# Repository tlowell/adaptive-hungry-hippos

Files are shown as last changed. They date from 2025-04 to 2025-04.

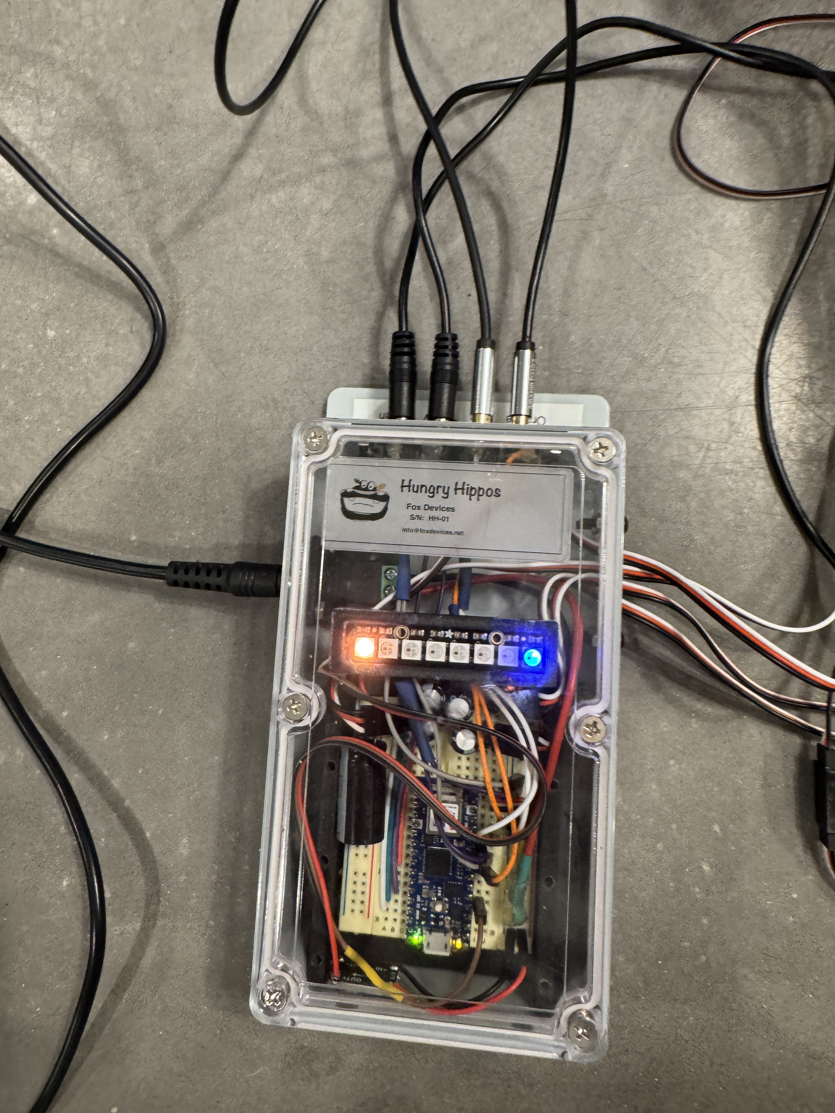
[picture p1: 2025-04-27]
images/lid on.JPG

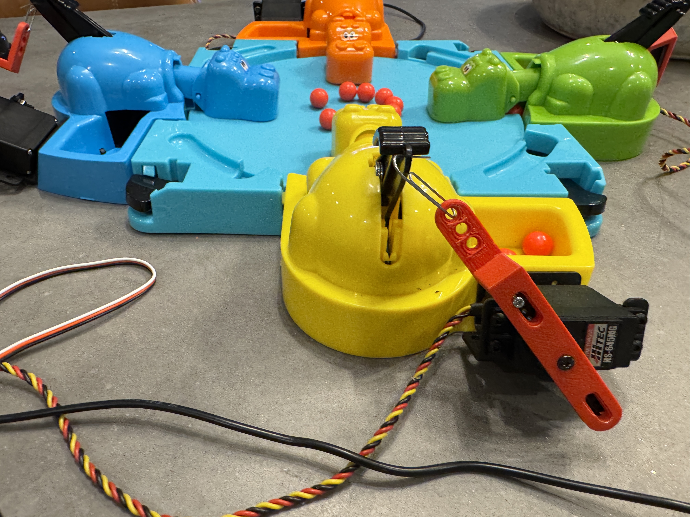
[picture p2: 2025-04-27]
images/servos attached.JPG

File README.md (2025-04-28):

# 🦛 Adaptive Hungry Hungry Hippos

Make the classic game playable using adaptive switches, an Arduino-compatible microcontroller, and servos.

---

## 📦 What's Included

- `code/` – Arduino sketch (`hippos.ino`)
- `docs/` – Build documentation (PDF/PostScript format)
- `images/` – Photos, wiring diagrams, illustrations
- `stls/` – 3D printable part files (.STL)

---

## 🛠️ What This Is

This repo documents how I modified **Hungry Hungry Hippos** for a child with physical limitations. It’s not a formal tutorial, but I’ve shared:

- My process
- Circuit diagrams
- Parts list
- Source code
- Printable hardware

The goal is to help others learn from it, adapt it, or remix it for their own accessible game projects.

---

## ⚠️ Please Note

I’m not an expert — just a hobbyist sharing what worked for me.  
You are ultimately responsible for verifying your own build.  
See the `LICENSE` section below for usage info.

---

## 💡 Getting Started

1. [ ] Start with the assembly instructions in 'hungry hippos - build guide.pdf' found in `docs/`
2. [ ] The build guide has links to everything else that's needed.
3. [ ] The build guide also provides a parts list with links
4. [ ] Some parts require 3D printing. The STL files for those are provided.
---

## 🧾 License

All files are licensed under [Creative Commons Attribution-NonCommercial 4.0 International (CC BY-NC 4.0)](https://creativecommons.org/licenses/by-nc/4.0/).  
You’re free to use and remix for **non-commercial purposes**, but please credit **Fox Devices, LLC**.

---

## 🙋 Questions or Feedback?

I’m always curious to hear how others use or adapt this project. If you spot a mistake, come up with a clever improvement, or want to share your build, I’d love to hear about it.

Feel free to:
	•	Open an issue
	•	Submit a pull request
	•	Or just reach out directly

Tom Lowell
📧 tclowell@gmail.com

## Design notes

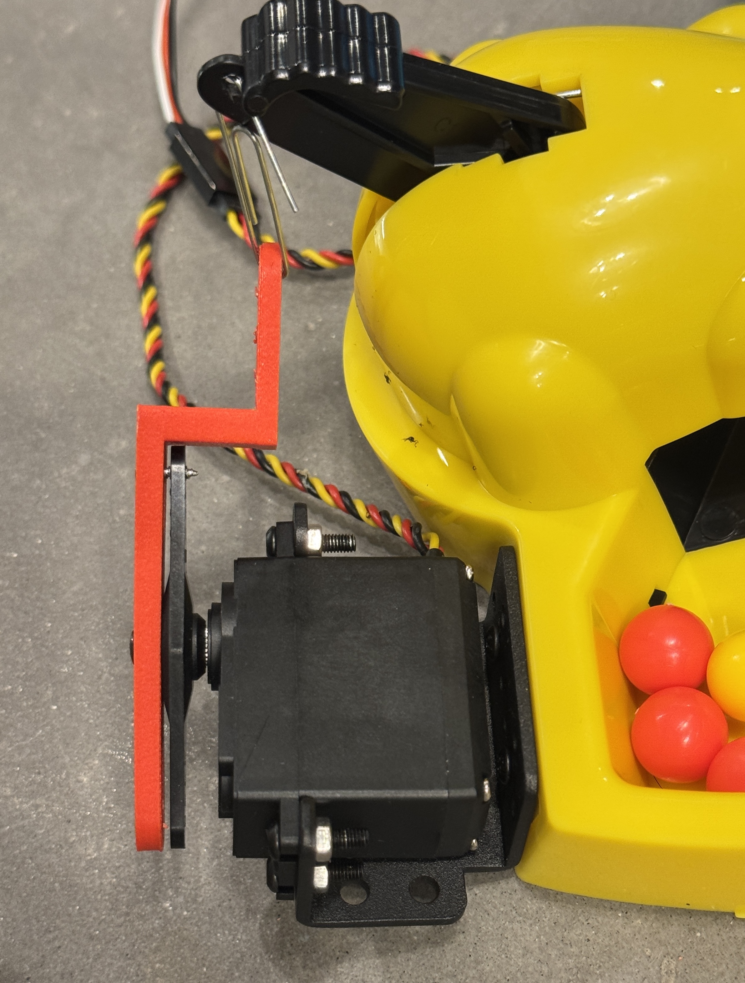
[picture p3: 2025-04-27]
images/servo mounted top view.JPG

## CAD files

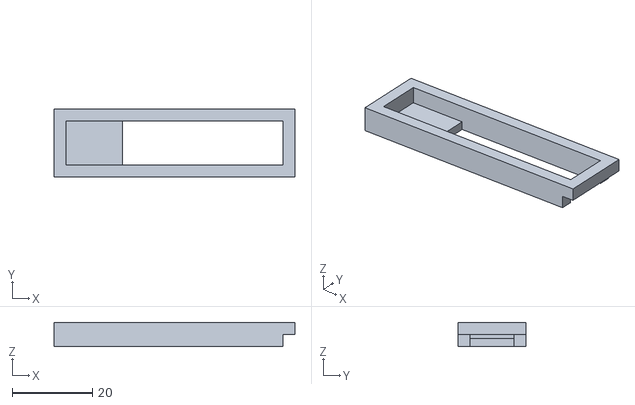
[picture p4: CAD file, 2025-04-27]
stls/hungry hippos LED holder.stl
60.0 x 17.0 x 6.00

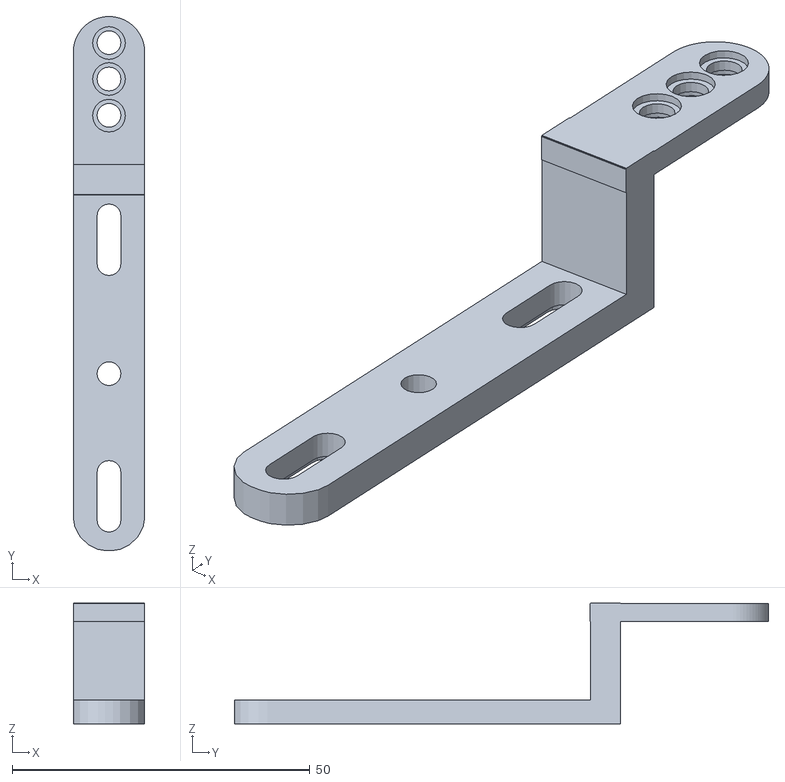
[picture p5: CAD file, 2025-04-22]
stls/hungry hippos offset servo arm long v1.stl
12.0 x 89.7 x 20.3

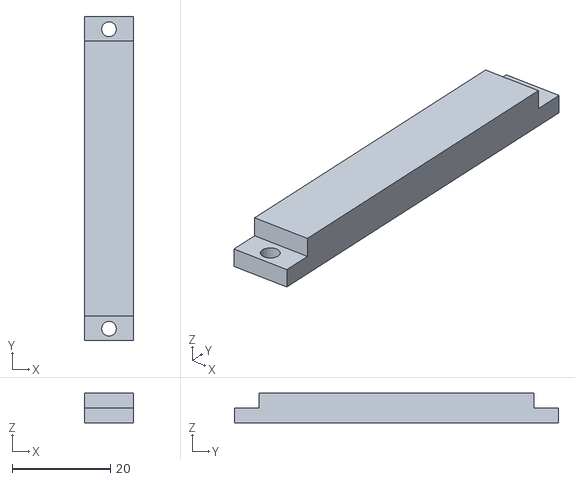
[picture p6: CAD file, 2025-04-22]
stls/hungry hippos mcu tray latch.stl
10.0 x 66.0 x 6.10

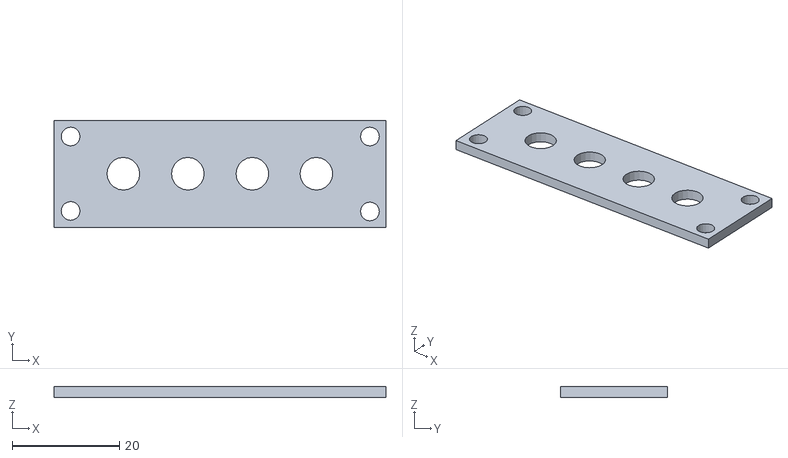
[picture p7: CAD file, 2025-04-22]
stls/hungry hippos switch jack plate.stl
62.0 x 20.0 x 2.00

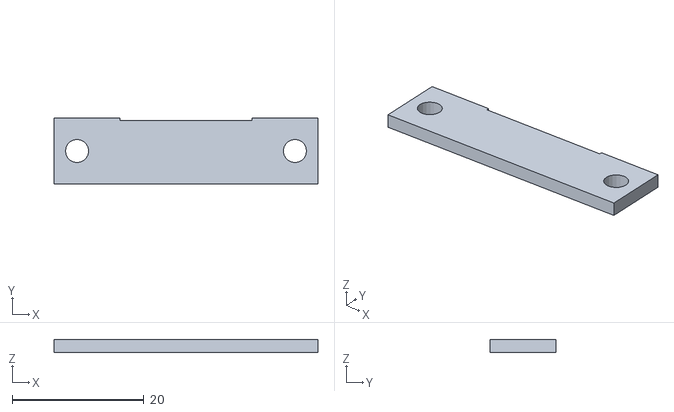
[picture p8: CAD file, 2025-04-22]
stls/hungry hippos servo wire plate v2.stl
40.0 x 10.0 x 2.00

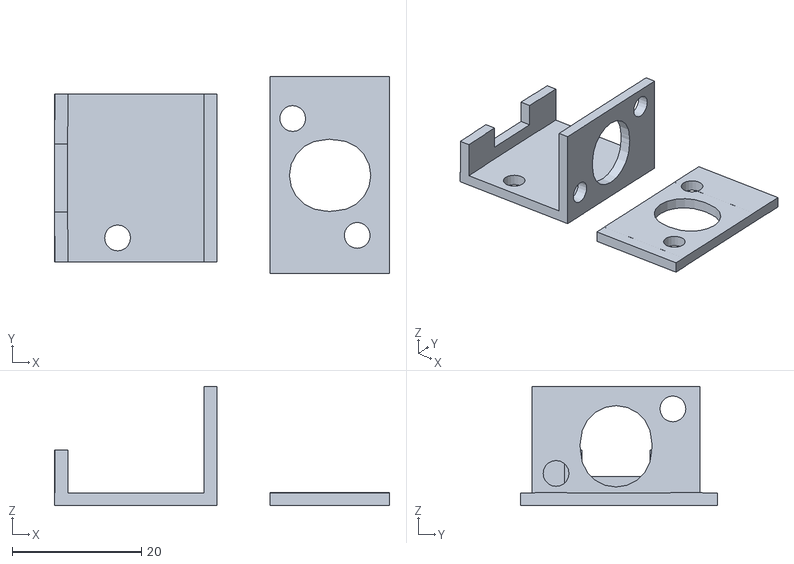
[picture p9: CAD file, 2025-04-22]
stls/hungry hippos power jack plate with mounting holes v2.stl
51.9 x 30.5 x 18.5

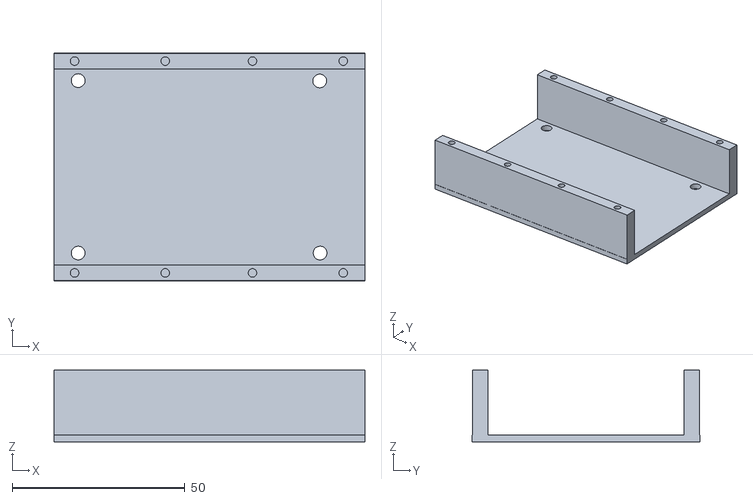
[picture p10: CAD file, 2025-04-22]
stls/hungry hippos mcu tray.stl
90.0 x 66.0 x 20.8

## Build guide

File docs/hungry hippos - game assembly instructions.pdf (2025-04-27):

Adaptive Hungry Hippos Game

Assembly Instructions

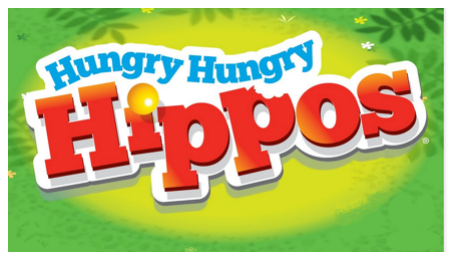
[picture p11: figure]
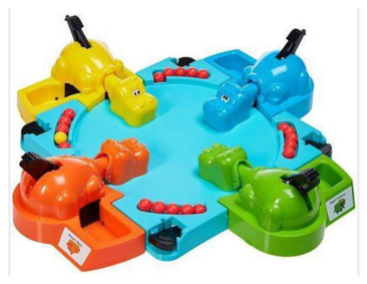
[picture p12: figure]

1. Insert the hippo assemblies into the game board (refer to the original game instructions for guidance).
2. Lay out the power supply and game controller so they’re within reach of both a wall outlet and the game board.
3. Connect the 4 hippo servo cables to the 4 servo cables that are attached to the case. Each cable attached to the case is labeled with a color. While you can technically connect them in any order, matching the colors ensures that the LED indicators in the case correspond to the correct hippo during gameplay.

Note: Two of the servo extension cables have extra length. To keep things tidy and avoid strain, rotate the game board so the hippos with longer cables are farther from the controller, and the hippos with shorter cables are closer.
4. Connect the four adaptive switches to the corresponding jacks on the end of the controller case. Each jack is labeled with the color of the hippo it controls. You can plug any switch into any jack.
5. Plug the power supply’s DC jack into the matching input on the game controller case.
6. After checking all cable connections, plug the power supply into a wall outlet.
7. The microcontroller should boot up within 10–15 seconds. A blue or green LED (depending on the starting mode) should be visible through the case lid.
8. The game is ready to play — just press the adaptive switches to control the hippos. (For full gameplay instructions, refer to the original game instructions)
9. Remember to unplug the game when not in use to avoid unnecessary strain on the servos

Notes:
- Check for servo heat: Occasionally touch each servo during or after gameplay. They should stay relatively cool in this implementation. If you notice one getting hot, unplug the game to give it a break (“let the hippos rest”) and check the servo’s mechanical connection or adjust the programmed open/close angles in the Arduino code (hippos/hippos.ino). Servos shouldn’t have to fight to hold position in this design.
- If a hippo becomes “bound up,” gently move it by hand to ensure the mechanical parts are operating freely.
- The servos may hum or “chatter” occasionally depending on their adjustment. However, they should not chatter loudly or continuously, as this can cause premature wear. If this occurs, you may need to adjust their physical connection to the hippos or fine-tune the programmed rotation angles in the Arduino code (hippos/hippos.ino).

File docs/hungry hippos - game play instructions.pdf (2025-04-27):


Adaptive Hungry Hippos Game

Gameplay Instructions

How to Set Up and Play

1. Plug in the adaptive switches and connect the servos.
2. Plug in the power supply.
3. Within 10–20 seconds, a green or blue LED under the electronics case lid will turn on.
4. The game is ready to play — just press the adaptive switches to control the hippos.

(For full gameplay instructions, refer to the original Hungry Hungry Hippos manual.)

Gameplay Modes

There are two modes that control how long the hippos remain extended when activated:
- Mode 1: The hippo remains extended for a fixed duration of ½ second before automatically retracting. (This duration can easily be adjusted in the code.)
- Mode 2: The hippo remains extended as long as the player holds down their adaptive switch, and retracts when the button is released.
Players can toggle between the two modes by double-tapping their adaptive switch within ½ second.
(This timing is also adjustable in the code.)
Mode 2 provides more direct control for the player, while Mode 1 may be easier for some children depending on their physical ability. The LED under the lid indicates the current mode: green for one mode, blue for the other.

Notes

- Check for servo heat:

Occasionally touch each servo during or after gameplay. They should stay relatively cool in this implementation. If you notice one getting hot, unplug the game to give it a break (“let the hippos rest”) and check the servo’s mechanical connection or adjust the programmed open/close angles in the Arduino code (hippos/hippos.ino). Servos shouldn’t have to fight to hold position in this design.

- If a hippo becomes “bound up”:

Gently move it by hand to ensure the mechanical parts are operating freely.

- Servo chatter:

The servos may hum or “chatter” occasionally depending on their adjustment. However, they should not chatter loudly or continuously, as this can cause premature wear. If this occurs, you may need to adjust their physical connection to the hippos or fine-tune the programmed rotation angles in the Arduino code (hippos/hippos.ino).

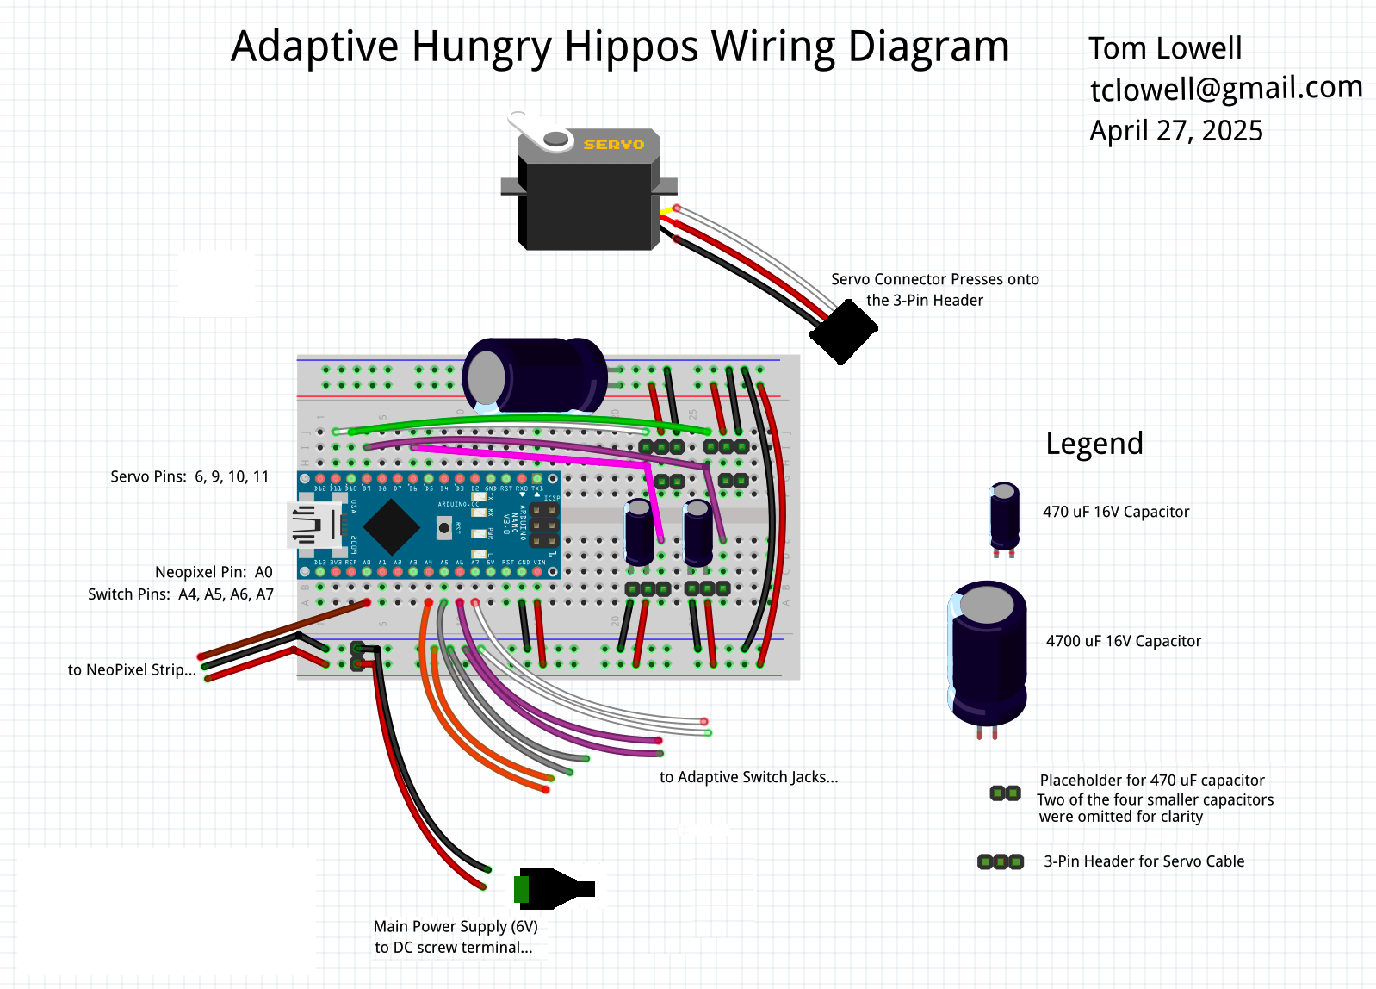
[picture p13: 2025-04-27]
images/hungry hippos - fritzing wiring diagram.png

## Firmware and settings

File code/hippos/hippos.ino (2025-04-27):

/*
 * hippos.ino v1.0.03
 *
 * Edit History
 *

 * v1.0.04 - moving to Arduino Nano 33 IoT for the power pin.
 * v1.0.03 - moving to ESP32-S3 (different servo library. Leverage builtin TFT)
 * v1.0.02 - Added servo tuning feature, tied to serial port.
 * v1.0.01 - initial creation
 *
 * Hungry Hungry Hippos – Adaptive Game Controller
 * Developed by Fox Devices, LLC
 *
 * There are 4 adaptive switches controlling 4 servos that are mounted to games pieces. The servos
 * normally remain in the "closed" state until a button is pressed. When pressed, the servo arm moves
 * to the "open" state. It remains open until either the button is released or for a preconfigured
 * time value like half a second.
 *
 * The code supports two modes for servo operation. In mode 1, the hippo head is extended for a fixed duration of time
 * and then retracts automatically. (This time duration can be set below in the line SERVO_OPEN_TIME = 500;) In mode 2, 
 * the hippo head remains extended until the user releases the button. Any user can toggle between modes by double-tapping
 * their switch within .5 seconds. The code will assure that only one person changes modes at a time. One of the LEDS
 * will indicate the current mode (green or blue).
 *
 * The switches are active low which means when not being pressed, the code will read a 1 on their
 * input pins but while pressed, the code will see a 0.
 *
 * The code lights a different colored LED whenever a hippo's button is pressed.  (orange for the organge hippo,
 * green for the green hippo, etc). In order for the code to know which color to use it assumes a specific
 * order of the adaptive switches controlling specific hippo servos. For this reason, the DC switch jacks and the
 * servo cables are labelled. The game will operate fine even if these are mixed up. It will just throw off
 * the color associations seen in the LED strip.
 *
 * Learn all about how to use neopixels in the Adafruit Neopixel Uberguide - https://learn.adafruit.com/adafruit-neopixel-uberguide/the-magic-of-neopixels
 *
 * The code also checks for commands on the serial port. This allows the user to fine tune servo 
 * response by trying new values for SERVO_OPEN_POS and SERVO_CLOSED_POS while the game is running.
 * For example, one can change the servo closed position to 65 degrees by typing "C65" into 
 * the input window in the Adruino IDE serial monitor. The command format is Oxx (for open) and Cxx for 
 * close. New values are not remembered and must be transferred manually to the appropriate lines below
 *
 * This technique is useful in early development when you're still fine-tuning motion ranges.
 * You can adjust values live via the serial monitor without needing to re-upload your sketch.
 * For a more permanent solution, update the values of SERVO_OPEN_POS and SERVO_CLOSED_POS in the code.
 * The code also debounces the switches. There is logic to avoid accidental double activiations of a switch
 * or sensing multiple switch activations when the user only pressed the button once.
 * 
 * This code is licensed under the Creative Commons Attribution-NonCommercial 4.0 International License (CC BY-NC 4.0).
 * 
 * You are free to use, modify, and share this code for personal, non-commercial use, provided that you credit Fox Devices, LLC as the original author.
 * 
 * Commercial use is not permitted without prior written consent.
 * 
 * For full license details, visit:
 * https://creativecommons.org/licenses/by-nc/4.0/
 */
 
#include <Adafruit_NeoPixel.h>
#include <Servo.h>

const int BUILTIN_LED = 13;  // Built-in LED
const unsigned long BLINK_INTERVAL = 2000;  // Total cycle time (2 seconds)
const unsigned long ON_DURATION = 100;     // LED on for 1 second
unsigned long previousBlink = 0;
bool ledOn = false;
const int NUM_HIPPOS = 4;

/******************************/
/*  Neopixel LED declarations */
/******************************/

#define NEOPIXEL_PIN A0      // Choose just about any free  pin
#define NUM_PIXELS   8        // Full strip length, even if you're only using 4
Adafruit_NeoPixel pixels(NUM_PIXELS, NEOPIXEL_PIN, NEO_GRB + NEO_KHZ800);  //neopixel object that maintains state
uint32_t hippoColors[4] = {
  pixels.Color(125, 50, 0),   // for when ORANGE_HIPPO switch is activated
  pixels.Color(0, 125, 0),     // for when GREEN_HIPPO  switch is activated
  pixels.Color(125, 125, 0),   // for when YELLOW_HIPPO switch is activated
  pixels.Color(0, 0, 125)     // for when BLUE_HIPPO   switch is activated
};
#define MODE_1_COLOR   pixels.Color(0, 0, 30)
#define MODE_2_COLOR   pixels.Color(0, 30, 0)
#define STATUS_PIXEL   7        // use one pixel for the mode status

#define OFF pixels.Color(0, 0, 0)

/*****************************************/
/*  Adaptive switch related declarations */
/*****************************************/

const int adaptiveSwitchPins[NUM_HIPPOS] = {A4, A5, A6, A7}; // Adaptive switch input pins (see breadboard)

const unsigned long DEBOUNCE_TIME = 50;     // in millisseconds. Shouldn't need to change. Makes sure button press is only seen once.
const unsigned long DOUBLE_TAP_WINDOW = 500; // in millisseconds, to detect and avoid accidental double-activation
bool buttonState[NUM_HIPPOS] = {false}; // Debounce tracking for each switch
bool lastButtonState[NUM_HIPPOS] = {false}; // Debounce tracking for each switch
unsigned long lastDebounceTime[NUM_HIPPOS] = {0}; // Debounce tracking for each switch
// Double-tap mode toggle tracking
unsigned long lastTapTime[NUM_HIPPOS] = {0}; // for each switch
int tapCount[NUM_HIPPOS] = {0};

/*******************************/
/*  Servo related declarations */
/*******************************/

const int servoPins[NUM_HIPPOS] = {6, 9, 10, 11};    // Servo output pins for Arduino Nano 33 IoT (see breadboard)
Servo hippoServos[NUM_HIPPOS]; // Servo objects, each one controls a hippo via a physical pin listed in servoPins[]

// ⚙️ NOTE: This implementation uses a single open/close value (below) for all 4 servos.
// If you'd like to tune each servo individually (for example, to account for mechanical differences),
// you can change SERVO_OPEN_POS and SERVO_CLOSED_POS from single int variables
// to arrays: int servoOpenPos[NUM_HIPPOS]; and int servoClosedPos[NUM_HIPPOS];
// Then update the code wherever SERVO_OPEN_POS or SERVO_CLOSED_POS is used
// to access the value specific to that servo (e.g., servoOpenPos[i]).
// This approach fits well with the current structure, which already uses index-based arrays.

int SERVO_OPEN_POS  = 0;   // Servo position when hippo head extends out. Change this as necessary.
int SERVO_CLOSED_POS = 75; // Servo position when hippo head returns. Change this as necessary.

enum ModeType { MODE_HOLD_TO_OPEN = 2, MODE_FIXED_DURATION = 1 };
ModeType mode = MODE_FIXED_DURATION; //game can operate in 2 different modes. Holding the servo open or timed.
//ModeType mode = MODE_HOLD_TO_OPEN; //game can operate in 2 different modes. Holding the servo open or timed.
const unsigned long SERVO_OPEN_TIME = 500;  // in millisseconds (adjustable for Mode 1 - Fixed Duration)
bool servoIsOpen[NUM_HIPPOS] = {false}; // Need to track servo timing if we're using  mode MODE_FIXED_DURATION
unsigned long servoCloseTime[NUM_HIPPOS] = {0}; // Need to track servo timing if we're using  mode MODE_FIXED_DURATION

/* Forward Declarations for all functions */
void setup();
void loop();
void processSerial();
void processServos();
void setOpenPosition(int pos);
void setClosePosition(int pos);
void setLEDs(int LEDnum, boolean new_state);
void toggleMode();
void waitForSerial(unsigned long timeout_ms = 3000);

void setup() {
  Serial.begin(9600);                     // start the serial port object so we can read and write to it
  waitForSerial(3000);  // Wait up to 3000ms (3 seconds) for Serial connection, then move on
  Serial.println("🐗 Hungry Hippos Controller Ready");
  Serial.println("Default Mode: MODE 1 (Fixed Duration)");
  pinMode(BUILTIN_LED, OUTPUT);
  digitalWrite(BUILTIN_LED, LOW);  // Start with LED off
  pixels.begin();       // Initialize NeoPixel LED strip
  pixels.clear();       // Make sure all pixels are off
  pixels.show();        // Push that update to the strip
  delay(200);
  for (int i = 0; i < NUM_HIPPOS; i++) { // loop thru all the servos and...
    pinMode(adaptiveSwitchPins[i], INPUT_PULLUP); // declare their I/O pin. PULLUP causes the pin to have a 1 value except while the button is pressed it's a 0.
    hippoServos[i].attach(servoPins[i]);       // associate that I/O pin with their server "object"
    hippoServos[i].write(SERVO_CLOSED_POS);    // set the servo arm to the closed position
  }
  pixels.setPixelColor(STATUS_PIXEL, MODE_1_COLOR);  // Change mode color on LED 7 so user knows what mode (green or blue)
  pixels.show();        // Push that update to the strip
}

void loop() {
unsigned long currentTime = millis();
bool anyServoOpen = false;

// need to know if any buttons are being pressed, so the blining heartbeat doesn't exteinguish the builtin LED.
for (int i = 0; i < NUM_HIPPOS; i++) {
  if (servoIsOpen[i]) {
    anyServoOpen = true;
    break;  // Exit early if any servo is open
  }
}

  if (!ledOn && (currentTime - previousBlink >= BLINK_INTERVAL)) {
    digitalWrite(BUILTIN_LED, HIGH);
    previousBlink = currentTime;
    ledOn = true;
  }

// only extinguish the builtin LED on the heartbeat timer if also no servo is being held open.
if (anyServoOpen) {
  digitalWrite(BUILTIN_LED, HIGH);  // Keep LED on if any servo is open
  } else {
    if (ledOn && (currentTime - previousBlink >= ON_DURATION)) {
      digitalWrite(BUILTIN_LED, LOW);
      Serial.println("in new code setting BUILTIN_LEF to OFF");
      ledOn = false;
    }
  }
  
  if (Serial.available() >= 3) {  // Wait for full 3-character command (like "C75") on serial port
      processSerial();
    }
  processServos();
}

/*********************/
/*  Helper Functions */
/*********************/

void processSerial() {
  char command = Serial.read();    // 'O' or 'C'
  char digit1 = Serial.read();     // First digit for servo degrees
  char digit2 = Serial.read();     // Second digit for servo degrees

  // NOTE: These changes are temporary and will not persist if the board is restarted.
  // To make permanent, update the SERVO_OPEN_POS and SERVO_CLOSED_POS constants in code.

  if ((command == 'c' || command == 'C'|| command == 'o'|| command == 'O') && // Check if all are valid ASCII digits
      isDigit(digit1) && isDigit(digit2)) {
    int value = (digit1 - '0') * 10 + (digit2 - '0');
    if (command == 'O' || command == 'o') {
      setOpenPosition(value);
    } else {
      setClosePosition(value);
    }
  } else {
    Serial.println("Invalid input. Format: Oxx or Cxx. Saw comand " + String(command) + String(digit1) + String(digit2));
  }
  while (Serial.available()) Serial.read(); // Clear any leftover bytes to keep things clean
}

void processServos(){
unsigned long now = millis();
  /*
   * Loop through each hippo/switch pair, using the loop index `i` to access elements in our arrays.
   * Note: `i` is just an index — it does NOT refer to an actual pin number.
   *
   * For example, when i == 3:
   *   adaptiveSwitchPins[3] == 4      → this means we’re reading from input pin 4
   *   servoPins[3]          == 10     → this means we’re writing to servo on output pin 10
   *   hippoServos[3]                  → this is the Servo object that was attached to pin 10
   *                                     in setup() via hippoServos[i].attach(servoPins[i]); 
   *
   * So when we see a LOW signal (button press) on pin 4, we move the servo connected to pin 10.
   * This pattern repeats for all 4 hippos, with each `i` controlling its corresponding pair.
   */

  for (int i = 0; i < NUM_HIPPOS; i++) { 
    bool reading = digitalRead(adaptiveSwitchPins[i]) == LOW; // Active LOW = button pressed
   
    if (reading != lastButtonState[i]) {  // Debounce logic for the buttons
      lastDebounceTime[i] = now;
      lastButtonState[i] = reading;
    }

    if ((now - lastDebounceTime[i]) > DEBOUNCE_TIME) {
      if (reading != buttonState[i]) {
        buttonState[i] = reading;  // Update debounced state
        if (buttonState[i]) { // ---------- Edge event (button just pressed) ----------
          if ((now - lastTapTime[i]) < DOUBLE_TAP_WINDOW) { // Double-tap logic
            tapCount[i]++;
          } else {
            tapCount[i] = 1;
          }
          lastTapTime[i] = now;
          if (tapCount[i] >= 2) {
            toggleMode(); // user did a double-tap to toggle modes. Le's do it!
            tapCount[i] = 0;
            for (int j = 0; j < NUM_HIPPOS; j++) { // Also reset other players' tap counts to prevent race toggles
              if (j != i) tapCount[j] = 0;
            }
          }

          if (mode == MODE_FIXED_DURATION) {   // Mode 1: Timed open, so open servo and start timing it
            Serial.println(String(i) + " is being pressed in MODE_FIXED_DURATION, open = " + String(SERVO_OPEN_POS));
            setLEDs(i, true);
            hippoServos[i].write(SERVO_OPEN_POS);
            servoIsOpen[i] = true;
            servoCloseTime[i] = now + SERVO_OPEN_TIME;
          }

          if (mode == MODE_HOLD_TO_OPEN) { // Mode 2: Just pressed → open, open servo but don't bother timing it.
            Serial.println(String(i) + " PRESSED → OPEN in MODE_HOLD_TO_OPEN, open = " + String(SERVO_OPEN_POS));
            setLEDs(i, true);
            hippoServos[i].write(SERVO_OPEN_POS);
            servoIsOpen[i] = true;
          }
        }

        else { // We're in mode 2 and saw an edge event (button just released) so close it! ----------
          if (mode == MODE_HOLD_TO_OPEN) {
            Serial.println(String(i) + " RELEASED → CLOSE in MODE_HOLD_TO_OPEN, closed = " + String(SERVO_CLOSED_POS));
            hippoServos[i].write(SERVO_CLOSED_POS);
            servoIsOpen[i] = false;
            setLEDs(i, false);
          }
        }
      }
    }

    // We're in Mode 1 and the servo duration timed out. Close it! ----------
    if (mode == MODE_FIXED_DURATION && servoIsOpen[i] && now >= servoCloseTime[i]) {
      Serial.println(String(i) + " is closing due to MODE_FIXED_DURATION, closed = " + String(SERVO_CLOSED_POS));
      hippoServos[i].write(SERVO_CLOSED_POS);
      setLEDs(i, false);
      servoIsOpen[i] = false;
    }
  }  
}

void setOpenPosition(int pos) { // User is temporarily redefining the open position of the servo
  if (pos < 0 || pos > 180) {
    Serial.println("Servo position must be between 0 and 180.");
    return;
  }
  SERVO_OPEN_POS = pos;
  Serial.println("Setting OPEN position to " + String(SERVO_OPEN_POS));
}

void setClosePosition(int pos) { // User is temporarily redefining the closed position of the servo
  if (pos < 0 || pos > 180) {
    Serial.println("Servo position must be between 0 and 180.");
    return;
  }
  SERVO_CLOSED_POS = pos;
  Serial.println("Setting CLOSED position to " + String(SERVO_CLOSED_POS));
}

void setLEDs(int LEDnum, boolean new_state){
  if (LEDnum < 0 || LEDnum > NUM_PIXELS - 1) {
    Serial.println("Neopixel number must be between 0 and " + String(NUM_PIXELS - 1) + ". " + String(LEDnum) + " was seen.");
    return;
  }
  Serial.println("In setLEDs():  LED[" + String(LEDnum) + "] to color[" + String(new_state) + "]");
 
  if (new_state){
    Serial.println("setting LED[" + String(LEDnum) + "] to color");
    pixels.setPixelColor(LEDnum, hippoColors[LEDnum]);  // Turn on LED
    digitalWrite(BUILTIN_LED, HIGH);
  }
  else{
    Serial.println("setting LED[" + String(LEDnum) + "] to OFF");
    pixels.setPixelColor(LEDnum, OFF);  // Turn on LED OFF
    digitalWrite(BUILTIN_LED, LOW);
  }
  pixels.show();     // Push to LED strip
  delay(10);
}

void toggleMode() { // toggle servos between  staying open a preset lenght of time or waiting for button release
  if (mode == MODE_FIXED_DURATION) {
    mode = MODE_HOLD_TO_OPEN;
    pixels.setPixelColor(STATUS_PIXEL, MODE_2_COLOR);  // Change mode color on LED 0 so user knows what mode
    Serial.println("🔄 Switched to MODE 2: Hold-to-Open");
  } else {
    mode = MODE_FIXED_DURATION;
    pixels.setPixelColor(STATUS_PIXEL, MODE_1_COLOR);  // Change mode color on LED 0 so user knows what mode
    Serial.println("🔄 Switched to MODE 1: Timed Press");
  }
  pixels.show();    // Push new LED color to LED strip
}

void waitForSerial(unsigned long timeout_ms) {
  unsigned long start = millis();
  while (!Serial && (millis() - start < timeout_ms)) {
    delay(10);
  }
}

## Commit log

2025-04-22 initial creation
    [hungry hippos mcu tray latch.stl, hungry hippos mcu tray.stl, hungry hippos offset servo arm long v1.stl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]
2025-04-27 Migrated to Arduino Nano 33 IoT processor and finished first draft of everything.
    [hungry hippos - fritzing wiring diagram.fzz, hungry hippos LED holder.stl]
